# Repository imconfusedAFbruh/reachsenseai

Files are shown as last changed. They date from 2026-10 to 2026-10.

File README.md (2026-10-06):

# ReachSenseAI

**Behind-the-back shoulder flexibility, measured in 3D.**

ReachSenseAI is a research measurement instrument in development that uses an iPhone's front TrueDepth camera and calibrated finger fixtures to estimate the gap or overlap between two middle fingertips during a behind-the-back shoulder flexibility test.

The design pairs each score with evidence about alignment, tracking, stability, and calibration—giving researchers a measurement they can inspect, repeat, and export.

> **Project status:** the native front TrueDepth sensor prototype and tested geometry core are available. Full rigid-body tracking/fusion, physical fixture acceptance, and research validation remain in development. No final accuracy claim has been established.

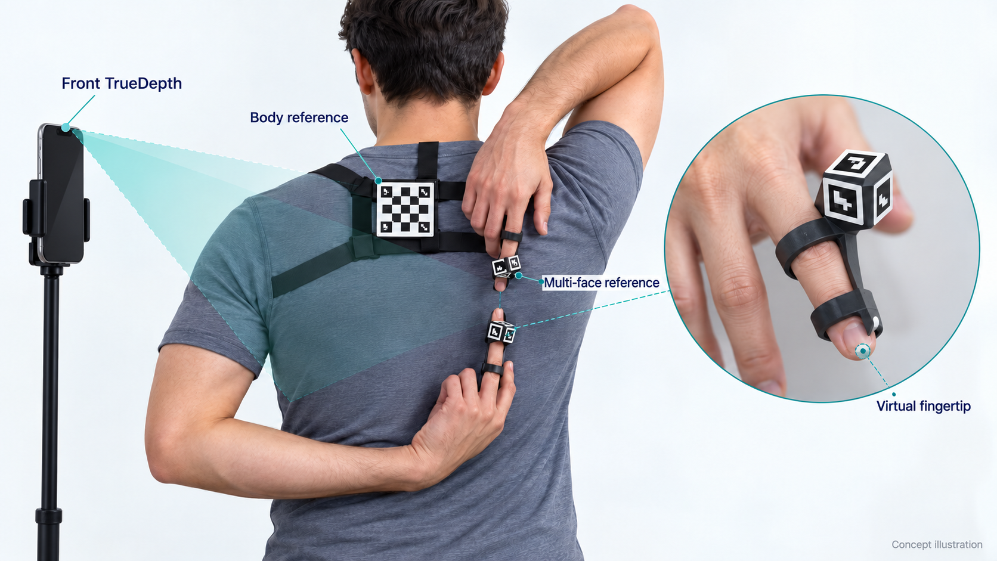
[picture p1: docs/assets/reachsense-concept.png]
ReachSenseAI concept showing a front TrueDepth camera on a stand, calibrated upper-back reference, multi-face middle-finger fixtures, and a virtual fingertip close-up


*Concept illustration of the planned setup. Fixture shapes, marker patterns, and mounting are illustrative; final geometry and performance require experimental validation.*

## What it measures

The participant reaches one hand down from above the shoulder and the other up from below. ReachSenseAI estimates the anatomical middle-finger endpoints in a coordinate frame registered to the participant's back.

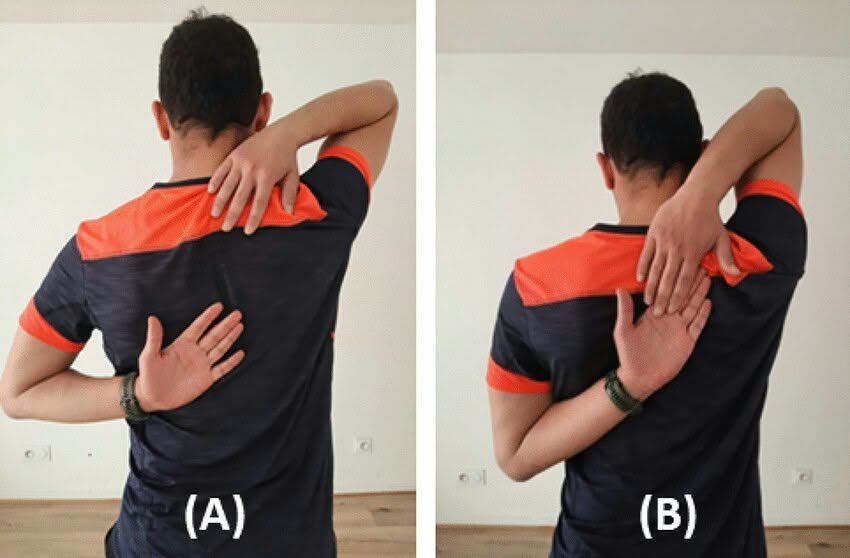
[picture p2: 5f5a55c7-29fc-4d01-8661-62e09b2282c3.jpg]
Reference illustration of the behind-the-back shoulder flexibility test


The primary score is **signed overlap along the body's upward axis**:

| Score | Meaning |
| --- | --- |
| Negative | A projected gap between the endpoints |
| Zero | Equal positions along the body axis |
| Positive | Projected overlap between the endpoints |

Sideways and depth offsets are recorded separately. Zero projected overlap does not establish physical contact, and fingers that appear aligned in an image may still be apart in depth.

## Designed for the difficult part of the test

### Fingertips can disappear without losing their reference

Overlap can hide one or both biological fingertips. Each fixture provides a calibrated virtual fingertip point, allowing its location to remain estimable while enough of the rigid reference is observed. If the reference becomes unobservable, the frame is rejected; a predicted point cannot silently become a valid measurement.

### Several faces contribute to one pose

Each finger fixture carries at least three uniquely identified markers on differently oriented faces. All usable visible corners contribute to one common 6-DoF rigid-body pose. Alternative faces provide observations during rotation and partial occlusion, with acceptance based on geometry, pose conditioning, residuals, and depth support rather than marker count alone.

### Depth adds a geometric check

Synchronized RGB and TrueDepth observations constrain the same known fixture geometry. Image corners, local depth surfaces, and temporal evidence contribute through quality-weighted fusion. Sensor disagreement and poor alignment trigger quality checks before a score is accepted.

### The score follows the participant's frame

A ChArUco reference on a calibrated upper-back mount establishes the body coordinate frame. The measurement is designed to account for camera tilt and participant orientation within validated conditions, rather than depend on a pixel gap in the camera image.

### Anatomical registration is part of the instrument

The proposed dorsal finger fixtures use two separated registration regions and a gentle fingertip stop. Their endpoint relationship, remount repeatability, and effects on posture and comfort must be tested. The upper-back mount receives its own registration calibration and drift checks.

### Every result has a record

The planned research exports include successful and unsuccessful attempts, per-frame geometry, quality metrics, rejection reasons, device details, and calibration and threshold versions. Summary CSV and detailed JSON support analysis and investigation of how a result was obtained.

## Measurement workflow

1. The researcher assigns one hand-up position per participant and keeps it consistent across visits.
2. With the phone on a stand, the researcher verifies calibration, fixture assignments, mounting, and fingertip seating.
3. After a familiarization attempt, the researcher starts each scored attempt. The app is designed to capture the median score over **one continuous second of passing observations**.
4. The researcher confirms seating after capture. A fixture swap or movement invalidates the affected trial and requires correction before restarting.
5. Up to **five scored attempts** are allowed to obtain **three valid trials**. Their median becomes the session score; an incomplete set receives no session score.

The provisional acquisition timeout is 15 seconds. Rest is researcher-controlled, and inter-attempt intervals are logged. Optional RGB/depth recording requires participant consent, uses local storage, and is retained indefinitely when enabled. Recorded media are included in exports only when explicitly selected.

## From observations to a score

```mermaid
flowchart TD
    Phone["iPhone front TrueDepth"] --> RGB["Synchronized RGB"]
    Phone --> Depth["Depth observations"]
    RGB --> Tags["Visible hand-fixture corners"]
    RGB --> Board["Observed ChArUco reference"]
    Geometry["Calibrated multi-face geometry"] --> Pose
    Tags --> Pose["One common pose per hand rigid body"]
    Depth --> Surfaces["Registered per-face 3D surfaces"]
    Pose --> Fusion["Quality-weighted pose fusion"]
    Surfaces --> Fusion
    Fusion --> Tips["Estimated virtual anatomical fingertips"]
    TipCalibration["Physical-jig endpoint calibration"] --> Tips
    Board --> Body["Registered body frame"]
    MountCalibration["Board-to-body mounting calibration"] --> Body
    Body --> Transform["Transform both tips into body coordinates"]
    Tips --> Transform
    Transform --> Score["Signed body-Y overlap + lateral/depth offsets"]
    Score --> QC{"Current observations and quality checks pass?"}
    QC -->|Yes| Window["Continuous 1-second window: median score"]
    QC -->|No| Reject["Reject frame; reset stable window"]
    Reject -. "Reacquire within attempt timeout" .-> Tags
    Window --> Seating{"Post-trial seating confirmed?"}
    Seating -->|Yes| Trial["Accepted trial"]
    Seating -->|No| Invalid["Invalidate attempt"]
    Trial --> Session["Median of 3 valid trials within 5 attempts"]
    Session --> Export["Summary CSV + detailed JSON"]
    Reject -. "Preserve failure evidence" .-> Log["Attempt and per-frame research records"]
    Invalid --> Log
    Log --> Export

    classDef sensor fill:#e8f5f4,stroke:#147d83,color:#123c43
    classDef calibration fill:#eef0fa,stroke:#626bb0,color:#293255
    classDef output fill:#e5f3e9,stroke:#39835a,color:#174329
    classDef failure fill:#fff0ee,stroke:#bd6258,color:#6f302b
    class Phone,RGB,Depth sensor
    class Geometry,TipCalibration,MountCalibration calibration
    class Trial,Session,Export output
    class Reject,Invalid failure
```

Current observations are required for both hand rigid bodies and the body reference. Temporal prediction can assist tracking, but cannot supply a valid measurement. An incomplete three-trial set has no session score; its attempt records remain exportable.

The planned implementation uses native iOS sensor processing with Swift, OpenCV, and AVFoundation/ARKit as appropriate to verified device support. Core measurement does not depend on AI hand-landmark estimation or cloud processing.

## Validation before performance claims

The next development gate is **physical finger-fixture feasibility**, supported by minimal capture and detection tooling. Marker dimensions, mounting geometry, sensor support, and usable observation conditions will be established experimentally.

Bench validation covers known distances, hand and body rotation, depth offsets, partial and complete reference occlusion, pose observability, and palm-to-palm overlap. Provisional engineering targets are MAE ≤ 5 mm, absolute bias ≤ 2 mm, and repeated static measurement SD ≤ 2 mm. These are requirements to test, not demonstrated performance.

Scored human research follows bench acceptance. Human repeatability and equipment effects must then be assessed. Published reference categories require additional evidence that their test definition matches the instrument's projected-overlap score.

## Explore the project

The [Android dual-camera APK](android/README.md) on `develop/android-dual-camera` tests simultaneous rear wide/ultrawide capture on the Samsung Galaxy S23 Ultra and exports timing evidence. GitHub Actions builds it from Windows without a local Android toolchain. Physical camera support and exposure synchronization still require checks on the phone; this capture app does not yet reconstruct stereo depth or issue a fingertip score.

Build the [native sensor prototype](ios/README.md) on a Mac with Xcode, then run it on the initial iPhone 15 Pro Max to record feasibility observations. The simulator cannot supply TrueDepth data. Inspect the adjustable [finger-fixture candidate and STL](hardware/README.md), and use the [frame inspection tool](scripts/feasibility/README.md) for exported bench observations. Follow the [implementation ledger](docs/implementation-progress.md) for verified software evidence and open physical/device gates.

| Document | Contents |
| --- | --- |
| [Measurement plan](plan.md) | Hardware, acquisition, geometry, QC, calibration, validation, and milestones |
| [Design decisions](docs/design-decisions.md) | Agreed protocol and architecture amendments |
| [Glossary](GLOSSARY.md) | Canonical measurement and instrument terminology |
| [Architecture decisions](docs/adr/) | Reasons behind consequential design choices |

Start with the measurement plan for the reproducible methodology. The current app is a sensor feasibility tool; it does not yet produce a shoulder-flexibility score.

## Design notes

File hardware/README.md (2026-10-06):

# Finger-fixture feasibility gate

The next physical gate is a repeatable anatomical relationship between each middle fingertip and its multi-face rigid reference. This directory supplies an adjustable CAD candidate and nominal geometry for experiments, not a validated or participant-ready fixture.

## Candidate design

`finger_fixture.scad` has two separated dorsal half-ring supports, retention slots, a bridge, a gentle fingertip stop, and a three-face marker mount. Candidate defaults are an 8 mm finger radius, 18 mm support spacing, 10 mm marker edges with 2 mm quiet-zone margins, and 35-degree side faces. These dimensions must be adjusted after fit, visibility, mass, comfort, and overlap tests. The mesh has no claim of joint immobilization or anatomical rigidity.

The physical frame R has origin at the nominal tip stop, +Y toward the distal fingertip, +Z dorsal, and +X lateral. Nominal face transforms and canonical corners come from the same dimensions. Actual prints, adhesive thickness, marker orientation, liner/strap choices, and fingertip registration require measurement and calibration.

```sh
python -m hardware.fixture_layout --output-dir hardware/generated/upper-candidate
python -m hardware.fixture_layout --radius-mm 9 --ids 31 32 33 \
  --output-dir hardware/generated/lower-candidate --openscad /path/to/openscad
```

Use OpenSCAD 2021.01 or newer to inspect/adjust the source and generate STL. Generated layout JSON is explicitly marked `candidate-unmeasured-not-valid-for-scoring`; it must not be passed off as verified jig calibration. Print the [candidate marker sheet](prototypes/marker-sheet.svg) at 100% and independently measure its black edges. [Marker generation/detection tools](../scripts/feasibility/README.md) support alternate experimental dimensions and dictionaries. Canonical marker tops must point toward fixture +Y for this nominal layout; verify actual mounting transforms.

## Required experiments before expanded fusion work

1. Measure actual finger/contact dimensions and select retention/liner materials. Document which middle/distal regions the supports register and which motions can alter the endpoint.
2. Independently measure virtual endpoint drift under insertion, finger flexion/rotation, sliding, repeated remounting, and palm-to-palm overlap. Separate mechanical movement from optical pose error.
3. Check hand/finger reach and comfort against the intended test; the stop/supports may change posture or prevent bare-finger contact. Record that equipment effect rather than assuming equivalence.
4. Test tag image area, corner geometry, blur, incidence angle, depth coverage, and occlusion at candidate camera distances. Establish usable observations from conditioning/residuals/depth support.
5. Measure every face transform and the anatomical endpoint in the common frame for each physical jig. Version the verified calibration and record jig identity, marker IDs/dictionary, marker orientation, geometry and verification evidence.
6. Prototype/calibrate a repeatable upper-back harness or multi-contact mount, including board-to-body registration and remount/angular drift.

Only demonstrated registration, visibility, and comfort evidence advances the physical gate. CAD rendering or passing software tests alone does not satisfy it.

## Rendered candidate

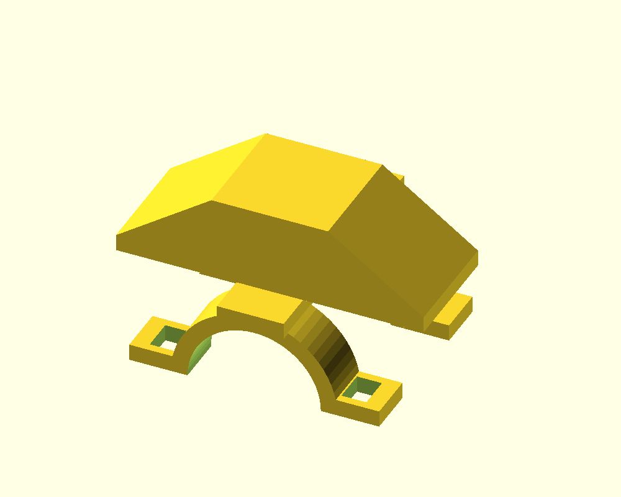
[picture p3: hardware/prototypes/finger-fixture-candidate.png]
Nominal finger fixture candidate


[STL mesh](prototypes/finger-fixture-candidate.stl) | [nominal face layout](prototypes/candidate-layout.json). Generated from the source with OpenSCAD 2021.01. The STL has 620 triangles, closed two-face edge topology, and nonzero volume. This is mesh evidence only; physical fit, seating rigidity and calibration remain untested.

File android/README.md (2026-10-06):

# ReachSense Dual for Android

This branch builds an Android APK that tests simultaneous rear wide/ultrawide capture on the researcher's Samsung Galaxy S23 Ultra. It uses one Camera2 logical session with two explicitly selected physical-camera YUV outputs. Device support is discovered and tested at runtime; a phone model or successful CI build is not hardware verification.

## Get the APK from Windows

1. Open [Android dual-camera APK runs](https://github.com/imconfusedAFbruh/reachsenseai/actions/workflows/android.yml), selecting the `develop/android-dual-camera` branch.
2. Open a successful run and download its **ReachSenseAI-android-debug** artifact. Extract the ZIP; the installable file is **ReachSenseAI-dual-camera.apk**.
3. Transfer the APK to the S23 Ultra and open it. Allow installation from the app opening the APK when Android requests it, then allow camera permission in ReachSense Dual.

Each artifact includes signature/manifest evidence, the source commit, SHA-256 digest, and timing/report test results. This is a signed development APK. GitHub runners generate debug signing keys; subsequent builds can have a different key and require uninstalling the old app. **Export all retained reports before uninstalling**, which removes app-private storage. Stable private signing is required before relying on in-place upgrades across research builds.

Verified software build: [run 37545350657](https://github.com/imconfusedAFbruh/reachsenseai/actions/runs/37545350657), source `d15a6c0`, artifact **ReachSenseAI-android-debug**. Build, lint, assertion checks, signature and downloaded-file integrity checks passed. S23 Ultra hardware verification remains pending.

## Run the device check

1. Tap **Check cameras**. Select a candidate pair using the physical IDs and estimated FOV. Choose the main wide and ultrawide rather than either telephoto lens. IDs are discovered, not hardcoded.
2. Start a **30-second test**. Both previews must receive current frames. Previews are downsampled and rendered at up to 5 fps to reduce load; every acquired image's timestamp is retained before preview throttling. The observed capture cadence is reported separately.
3. Cover each rear lens individually. Only its assigned preview should be obstructed. Assign A/B to wide/ultrawide and confirm each covered-lens check while the run is active. Repeat a run if there was insufficient time to confirm.
4. Export the selected JSON report using Android's document picker. Capabilities, failed sessions, interrupted runs and successful captures remain separately selectable. No image pixels are stored or exported.
5. Review both stream counts and cadence, unmatched/overflow/rejected observations, capture failures, physical metadata availability, and synchronization classification. Session rejection, disconnect and a three-second stream stall terminate the run with a reason; an early Stop or backgrounding saves an interrupted run.

The pairing filter starts at 5 ms and is adjustable. It is exploratory, not a validated stereo threshold. Same-request image timestamps may be equal even when actual exposures are not synchronized. Missing physical metadata remains missing, and ambiguous timestamp associations are explicitly rejected. Exposure/frame durations, rolling-shutter skew and physical timestamps are retained when provided. Physical timestamp differences are calculated only when both sensors report the comparable REALTIME timestamp source.

If local storage fails, pending reports remain available across screen rotation and new checks are blocked until they are exported. Keep the app open and export every pending report: these fallback copies are in memory and cannot survive the app process being killed while storage is unavailable. Export failures leave the pending copy available for retry.

Approximate/unknown synchronization requires an optical timing experiment with a controlled flashing target or motion. Even hardware-calibrated synchronization needs optical checks and stereo calibration before declaring stereo suitability. This APK does not reconstruct depth, track fixtures or issue fingertip/clinical scores. It establishes capture evidence for that next stage.

## Build and checks

GitHub Actions requires no Android installation on the researcher's Windows computer. Pushes touching `android/` or its workflow trigger checks, build, lint, signature verification and artifact upload. Manual dispatch may require the workflow to exist on the default branch; branch pushes work for this development branch.

With Java 17 and an Android SDK installed, use Gradle 8.11.1: `gradle -p android assembleDebug lintDebug`. Build configuration pins AGP 8.9.2 and SDK/build tools 35. Runtime code uses only platform APIs, with API 28 as its minimum.

The standalone assertions in `checks/` exercise actual timing pairing and JSON report persistence without a camera or emulator. Their JSON test library is pinned to `org.json:json:20240303` and checksum-verified in CI; the APK uses Android's built-in JSON implementation. Real camera support, lens identity, stream timing and interruption behavior still require the S23 Ultra device checklist in the approved plan.

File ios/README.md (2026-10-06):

# Native sensor prototype

This is Milestone 1 software for front TrueDepth feasibility work. It is not yet the full measurement app and produces no flexibility score.

## Build from Windows with GitHub Actions

Open the [native workflow](https://github.com/imconfusedAFbruh/reachsenseai/actions/workflows/native.yml), choose **Run workflow**, select `develop/rgb-web` (which contains the IPA packaging update), and run it. The workflow runs Swift core checks, builds the Release iPhone app and simulator target on a cloud Mac, packages the device app, verifies the IPA structure and ARM64 executable, and uploads `ReachSenseAI-unsigned-<commit>` under the completed run's **Artifacts**.

Download and unzip that artifact ZIP to obtain `ReachSenseAI-unsigned.ipa`. This is an **unsigned native TrueDepth sensor prototype**, not the full measurement app or the browser application. It must be signed before installation. Windows users can sign and install it using [Sideloadly](https://sideloadly.io/) and their own Apple Account. Free-account signing requires periodic refresh; successful compilation/package verification does not establish physical-device capture support. Keep downloaded artifacts locally for your research; GitHub artifact retention is finite.

The build needs no Apple signing secrets or Apple Account credentials in GitHub. Research recording consent and local export behavior remain as described below.

First verified build, 2026-10-07: [run 37538730987](https://github.com/imconfusedAFbruh/reachsenseai/actions/runs/37538730987), source `ab7edecb703eadaa34a75b43c7a1d884e24b739d`. All workflow jobs passed. The downloaded IPA was independently checked on Windows for ZIP integrity, the iPhoneOS platform, camera permission description and ARM64 Mach-O executable. Size: 162,076 bytes. SHA-256: `c884a4224df2328e03b1a38dc07c1d3553c5f2395a552f3f41d24585196d6621`. Signing, installation and real-device capture remain unverified.

## Build locally on a Mac

Requires Xcode with the iOS 17+ SDK and XcodeGen 2.43 or newer. The app uses the local `ReachSenseCore` Swift package.

```sh
brew install xcodegen
cd ios
xcodegen generate
open ReachSenseAI.xcodeproj
```

Set your signing team in Xcode and run the `ReachSenseAI` scheme on the initial iPhone 15 Pro Max. Other models in the requested iPhone 15 Pro Max–iPhone 18 range remain candidates until exact-device runtime support and capture quality are verified. There is no rear-camera fallback. The simulator can check the build/UI but cannot supply TrueDepth observations.

## First-device acceptance

1. Grant camera permission and start capture. Confirm front RGB and depth views change together, unmirrored, with compatible raw orientation.
2. Verify hardware ID, dimensions, timestamp skew, received/dropped counts, calibration delivery, and valid depth coverage.
3. Inspect a known-distance bench target at 300, 400, 500, and 600 mm; these are candidate validation distances, not claimed operating guarantees.
4. Explicitly authorize bench/consented RGB-depth recording, enter independently measured reference distance and target/angle notes, and save repeated paired frames.
5. Share selected JSON files to a research workstation. They contain lossless RGB PNG, contiguous float32 little-endian depth, timestamps, intrinsics, extrinsics, forward/inverse lens-distortion data, and sensor accuracy/quality labels.
6. Deny permission, interrupt/background capture, stop/restart, and cover/remove targets. Verify stale/rejected previews clear, capture does not resume automatically after interruption, a pending permission grant cannot restart stopped capture, no stale frame is saved, and no invalid depth becomes a 3D point.

The point estimate uses reference-dimension-scaled intrinsics and inverse radial mapping from an observed distorted pixel to a rectilinear ray. Stored calibration must be verified against known geometry; sensor observations and software tests do not establish measurement accuracy. Depth filtering is disabled to retain invalid samples/noise for characterization. The 5 ms pair-skew limit is an acquisition diagnostic, not a bench-derived research-QC threshold.

Apple extrinsics describe camera-to-reference-camera geometry: translation is in millimeters and rotation is unitless; the reference camera is not assumed to be RGB. Exported depth and point coordinates are in meters.

Raw frames are saved under Documents/Feasibility with no automatic deletion. The app requests system backup exclusion on both the directory and each saved file; Apple treats this flag as backup guidance, not a guarantee against every backup method. There are no automatic app uploads. Researchers must control media consent and explicit exports. No recording happens merely by opening the camera preview.

## Automated verification

```sh
swift test --package-path ..
xcodegen generate
xcodebuild -project ReachSenseAI.xcodeproj -scheme ReachSenseAI \
  -destination 'generic/platform=iOS' CODE_SIGNING_ALLOWED=NO build
```

CI exercises the core behavior and compiles both device and simulator targets; physical-camera acceptance remains mandatory.

Calibration conventions follow [Apple camera extrinsics](https://developer.apple.com/documentation/avfoundation/avcameracalibrationdata/extrinsicmatrix). Backup handling follows [Apple backup guidance](https://developer.apple.com/documentation/foundation/optimizing-your-app-s-data-for-icloud-backup).

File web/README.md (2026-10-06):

# ReachSense RGB Lab

Static browser research prototype on the `develop/rgb-web` branch. GitHub Pages serves it; a dedicated worker processes RGB camera frames locally using pinned OpenCV.js 4.13. No server image processing or TrueDepth access is involved.

```mermaid
flowchart LR
  RGB[Calibrated RGB camera] --> Tags[ArUco corner detection]
  Geometry[Known noncoplanar fixture geometry] --> Pose
  Tags --> Pose[One common 6-DoF pose per fixture]
  Pose --> Tips[Calibrated virtual fingertips]
  Back[Calibrated body-reference pose] --> Body
  Tips --> Body[Participant body frame]
  Body --> Score[Signed lower-Y minus upper-Y overlap]
  Score --> QC[Quality + alignment + one-second window]
  QC --> Record[Operator seating check + local record]
```

Import a schema-1 JSON calibration bundle, enter the participant's anonymous study ID, choose the camera and confirm its lens/settings match calibration. Start the camera, check physical assignments and fingertip seating, then start each attempt. Confirm seating again after automatic capture. Three valid trials produce a position-specific median; five scored attempts without three valid trials leave the position incomplete. Familiarization is recorded separately. Stop or report changed assignments to invalidate and pause the affected attempt.

The supplied `examples/exploratory.json` demonstrates the format only. It is **not a camera or anatomical calibration** and cannot produce accepted trials. Actual camera intrinsics/distortion, metric face corners in detector corner order, anatomical fingertip offsets, fixture versions, body registration and bench-derived quality thresholds must be supplied by the researcher. Verified camera/fixture statuses, fixture evidence, body registration evidence and a validated threshold profile with evidence are required to enable research acceptance. These declarations are researcher-controlled; the software does not independently certify them.

Initial support requires three-dimensional, noncoplanar visible geometry for each hand fixture and the body reference. Planar-only observations are rejected. The solver checks joint reprojection residuals, normalized pose-Jacobian conditioning, positive camera depth and three LM starting points for competing poses. **This multistart check is not an exhaustive proof of unique pose.** Bench validation must establish supported visibility and conditioning limits. No predictions replace missing observations. ΔX and ΔZ are reported separately; zero projected Y does not imply contact.

Camera bindings include resolution and operator confirmation of lens, focus, zoom, crop and mounting. The browser cannot reliably lock or identify all optical settings on every device. Any incompatible setting or fixture/endpoint movement requires recalibration. Browser estimates lack independent depth evidence. Phone performance, physical accuracy, repeatability, equipment effects and compatibility with clinical norms remain unverified. The 10–15 processed fps objective is provisional. The live UI reports actual throughput, compute time and observation age.

IndexedDB retains sessions without automatic deletion, but browsers can evict storage. Export JSON for durable per-frame poses, quality, failures and full calibration records; CSV provides attempt summaries. Optional consented RGB snapshots are stored only for attempts when consent is selected before capture, with indefinite local retention; JSON includes them only when explicitly selected for export. No RGB video or depth recordings are implemented. Saved records remain available to exports after reload. A storage error stops capture and allows emergency export of the in-memory session.

## Checks and local preview

`npm ci`, `npm test`, `npx playwright install chromium`, `npm run browser-test` from this folder. Serve this folder through a local HTTP server, for example `python -m http.server 8080 --directory web` from the repository root. Camera access requires localhost or HTTPS. Assets use relative URLs for the GitHub Pages project subpath.

GitHub Actions runs the core and actual browser checks and publishes this folder from `develop/rgb-web`. The native instrument remains a separate architecture on the main branch.

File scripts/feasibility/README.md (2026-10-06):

# Feasibility observation tools

Python 3.10+ is sufficient; there are no third-party dependencies.

```sh
python -m scripts.feasibility.inspect_frame path/to/frame.json
python -m scripts.feasibility.inspect_frame path/to/frame.json --extract-dir data/raw/frame-001
```

This decodes the iOS export, verifies format/units/dimensions, retains invalid sensor values in the raw binary, and reports robust center-region depth statistics. Optional extraction writes lossless RGB, contiguous float32 little-endian depth, and capture metadata into a new directory.

Only add `--reference-is-axial-plane` when the entered independent reference is the axial camera depth of a planar target that fills the analyzed region. The default report deliberately gives no bias estimate. Relative sensor depth never produces a metric-bias claim. Spatial depth SD within one image is not temporal sensor repeatability or fingertip measurement accuracy.

Collect repeated physical observations at candidate distances, angles, and surfaces. Use recorded timestamps/device IDs/calibration to investigate synchronization, invalid-depth coverage, bias, and remount effects. No sample export or fabricated validation dataset is supplied.
# Marker experiments

Install the pinned OpenCV tool dependency in a virtual environment:

```sh
python -m venv .venv
# Windows: .venv\Scripts\activate; macOS/Linux: source .venv/bin/activate
python -m pip install -r scripts/feasibility/requirements.txt
python -m scripts.feasibility.markers generate --output-dir hardware/generated/artwork
python -m scripts.feasibility.markers detect observation.json \
  --expected-ids 21 22 23 31 32 33
```

Generation writes an A4 SVG and an artwork manifest. The default candidate uses `DICT_4X4_100`, IDs 21/22/23 and 31/32/33, a 10 mm black marker edge (including its black border), and a 2 mm white quiet zone on every side. Dictionary, IDs and dimensions are configurable for experiments. IDs must remain unique across both jigs and the eventual body reference. The checked-in [candidate sheet](../../hardware/prototypes/marker-sheet.svg) is ready for printing at 100% scale; measure the actual black edges afterward. Quiet zones must remain white and unobstructed. This artwork is not measured fixture calibration.

Mount each marker with its canonical top pointing toward fixture +Y, as assumed by the candidate geometry. Confirm the ID, dictionary, orientation and measured face transform in calibration; do not infer them from a rendered illustration or printed label.

Detection accepts an RGB PNG/JPEG or one native feasibility JSON export. It reports subpixel-refined canonical corners in order TL/TR/BR/BL, marker area, minimum edge length, expected-ID flags, duplicate IDs and rejected quadrilaterals. Corner coordinates refer to the raw distorted RGB image; a rotated marker's canonical TL is not necessarily the image's top-left corner. These are image observations, without pose estimation or depth fusion. `measurement_valid` is always false. Detector defaults are not validated research thresholds, and no visible-tag count establishes reliable rigid-body observability.

By default the report prints to stdout without storing another image. Explicit `--output-dir NEW_DIRECTORY` saves a JSON report and an RGB annotation; use only authorized bench/consented images. Existing output directories are refused. Reports include OpenCV/NumPy versions, source SHA-256, and the original frame ID for native exports. Retain the source export to recover its calibration and sensor metadata.

For fixture testing, record distance, lighting, incidence angle, hand configuration, blur and occlusion along with the observations. Determine supported conditions experimentally. Digital marker checks do not establish physical detection performance, image/depth registration, endpoint rigidity or instrument accuracy.

Marker generation, canonical corner ordering and detection follow [OpenCV's ArUco documentation](https://docs.opencv.org/4.13.0/d5/dae/tutorial_aruco_detection.html).

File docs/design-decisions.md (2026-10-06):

# Design interview decisions

This log records the grill-with-docs decisions and their subsequent amendments. Later decisions supersede conflicting earlier entries. The user's latest attached instruction authorizes reconciliation of the methodology with the multi-marker architecture; experimental prerequisites remain unverified and software implementation is outside this documentation update.

## Round 1 — Accepted

1. Report an anatomical fingertip score using calibrated jig geometry; distinguish the jig tracking reference from the anatomical endpoint.
2. Accept two finger caps and a back reference for the first research prototype, and experimentally assess their effects on reach and comfort.
3. Make the first release a research measurement tool. Export the signed score and quality evidence; defer fitness categories until the reference table's source, units, applicable population, and boundaries are established.
4. Begin with a fixed phone stand and a trained operator.

## Round 2 — Accepted

5. Define the anatomical endpoint as the furthest point along the middle finger's length. Seat it gently against the cap's internal stop, calibrate the stop relative to the marker, and check seating before each trial.
6. Define the primary score as signed body-Y overlap: negative for a projected gap and positive for projected overlap. Report sideways/depth offsets separately and reject poses outside validated alignment limits. Zero projected overlap does not establish physical contact.
7. Measure right-hand-up and left-hand-up positions separately. Record the upper hand for every trial and do not average results across positions.
8. Assess equipment effects as a separate validation requirement. Describe measurements as a jig-assisted test and defer comparison with bare-hand reference categories until equipment effects are assessed.

## Round 3 — Accepted and pending

9. Accepted in round 4: provisional bench engineering targets are MAE <= 5 mm, absolute bias <= 2 mm, and static repeated-measurement SD <= 2 mm across agreed test conditions. These are requirements to test, not demonstrated accuracy claims. Report rejection/failure rates alongside accepted-measurement accuracy.
10. Use one familiarization attempt followed by three valid trials per position. Save every trial, including unsuccessful attempts, and use the median of the three valid trials as that position's session score.
11. Invalidate an affected trial if a cap shifts, reseat the cap, and restart. Require an operator seating check before and after each trial; marker visibility alone does not prove anatomical seating.
12. Always retain per-frame geometry, quality metrics, rejection reasons, and calibration identifiers. RGB/depth recording is an explicit research option requiring participant consent, local storage, and a defined retention period; that period remains unresolved.

## Round 4 — Accepted and pending

13. Allow at most five scored attempts per position to obtain three valid trials. Preserve all attempts. If fewer than three trials are valid, mark the position incomplete and do not issue a position session score. The familiarization attempt is separate from the scored-attempt limit.
14. The researcher operates the phone on the fixed stand. In round 6, the user selected one hand-up position per participant, kept consistent across visits. This supersedes Q7's requirement to measure both positions; record the selected upper hand. Starting-side balancing was not accepted.
15. Store retained research data, including optional RGB/depth recordings, indefinitely. This supersedes the unresolved retention period in Q12; optional recording still requires explicit participant consent and uses local storage. No automatic time-based deletion is planned.

## Round 5 — Accepted and pending

16. Rest between attempts is left to the researcher's discretion. No fixed or minimum rest interval has been accepted.

## Round 6 — Accepted and pending

17. No exact iPhone model has been selected. In round 7, front TrueDepth was confirmed as the prototype sensor requirement; verify synchronized RGB/depth capture support on the selected device before implementation proceeds beyond feasibility work.

## Round 7 — Accepted and pending

18. Keep front TrueDepth as the prototype requirement and confirm capture support on the chosen device before proceeding.
19. The researcher assigns each participant's hand-up position under the study protocol, records the upper hand at enrollment, and keeps it consistent across visits.
20. Notify and pause if jigs are swapped during the same session, invalidate the affected trial, and require the researcher to confirm jig assignments and seating before restarting. Calibration stays attached to the physical jig ID.

## Round 8 — Accepted

21. Use provisional test ranges of 300–600 mm camera distance and -100 to +100 mm signed body-Y overlap. Evaluate the accepted accuracy targets throughout the ranges and narrow the supported operating range if validation fails.
22. Block measurement when a required jig calibration is missing or its geometry has changed. Store a calibration version with every trial, and require recalibration after marker movement, damage, or endpoint changes.

## Round 9 — Accepted and pending

23. Derive quality thresholds from bench validation and version them. Prevent overrides from producing valid scores, and allow failed attempts to be saved for investigation.
24. Require one continuous second of passing quality checks for capture. Any required check failure breaks continuity and requires a new passing interval. Within-window aggregation was accepted in Q27.
25. The researcher starts each attempt, the app captures automatically when a valid stable window is available, and the researcher then confirms seating. Acceptance remains subject to the previously required before/after seating checks.
26. Accepted in round 10: export summary CSV plus detailed JSON containing all attempts, per-frame geometry, quality metrics, rejection reasons, selected upper hand, device details, and calibration/threshold versions. Include optional RGB/depth recordings only when explicitly selected for export.

## Round 10 — Accepted

27. Use the median signed body-Y overlap across the continuous one-second passing window. Restart the window after a required quality check fails. Accept the captured trial only after the post-trial seating check passes.
28. End an attempt after a provisional 15 seconds without successful capture, preserve it as unsuccessful with its failure reasons, and count it toward the five-scored-attempt limit. The researcher can stop earlier. The timeout applies to acquisition, not the subsequent seating confirmation.

## Round 11 — Accepted and pending

29. Require static-distance, depth-offset, and rotation bench acceptance before scored human research measurements. Permit consented setup and comfort pilots earlier but label their measurements exploratory. After bench acceptance, assess human repeatability and equipment effects before accuracy claims or comparison with bare-hand reference categories.
30. Select marker dimensions, cap sizes, endpoint materials, and back-reference mounting through feasibility experiments. Require marker visibility throughout the pose, repeatable fingertip seating, secure back-reference mounting, and acceptable comfort. Document chosen geometry and calibration before bench validation.
31. Accepted after clarification: automatically record attempt timestamps and the interval from the end of one attempt to the start of the next. Rest duration remains at the researcher's discretion; the recorded interval is elapsed time between attempts and may include setup or adjustments.

## Outstanding branches

None at the current design level. The subsequent methodology-update instruction authorizes document reconciliation; experimental prerequisites below remain required work.

## Final architecture amendment — Authorized methodology update

The attached methodology instruction replaces the original single-marker-per-fingertip architecture with two rigid 3D structures, each containing at least three uniquely identified planar fiducials on differently oriented faces. Estimate one common pose from all usable visible corners and per-face depth geometry; do not average independent marker poses. Calibrate every face transform and the virtual anatomical endpoint in a common frame for each physical jig.

Biological fingertip visibility is not required. Sufficient current observations of both rigid bodies and the body reference are required for valid frames; purely predicted or extrapolated points cannot enter the measurement window. Expand validation to hand rotation, marker-face occlusion, hidden fingertips, overlap/palm-to-palm poses, depth offsets, and body rotation, and report performance by visibility and viewing conditions.

Retain the finalized one-second continuous median, trial/session workflow, indefinite retention, and explicit optional media export. Retain Q6's zero-as-equal-body-Y definition rather than the attachment's illustrative zero-as-touch wording, because projected overlap alone does not establish physical contact. Dimensions, minimum usable face visibility, optimizer details, and quality thresholds remain experimental choices. The update preserves the research objective and the 30-section plan structure.

## Methodology review refinements

1. Prototype a dorsal finger fixture with at least two separated anatomical registration regions, such as the middle and distal phalanges, plus the fingertip stop. Verify resistance to endpoint-changing flexion, rotation, and sliding; multiple supports do not establish rigidity without evidence. Evaluate posture/reach and comfort effects independently.
2. Require measurement-definition equivalence with any source normative test, in addition to equipment-effect validation, before applying its categories. Preserve ΔX/ΔZ to investigate alignment-dependent disagreement.
3. Treat the upper-back mount as a calibrated fixture with repeatable harness/multi-contact registration, a versioned board-to-body transform, and drift/remount verification. A visible board or clothing attachment alone does not establish anatomical alignment.
4. Add a dedicated complete rigid-body observability experiment. Derive acceptance from conditioning/ambiguity, reprojection residuals, observed corner geometry, and depth support rather than marker count alone; validate the rule on separate conditions/repetitions.
5. Make physical finger-fixture feasibility the next development gate. Permit minimal sensor/detection tooling to support experiments, while deferring expanded software and finalized dimensions until registration evidence supports the fixture.

## Experimental prerequisites after review

The following are intentionally determined by feasibility work and validation, not assumed to be settled design values:

- Exact iPhone model and verified front TrueDepth capture support.
- Marker dimensions, endpoint materials, cap sizes, and reference mounting geometry.
- Calibration verification procedures, jig seating/remount repeatability, and marker visibility across the pose.
- Bench-derived quality limits, including lateral/depth alignment limits, with versioned threshold sets.
- Detailed validation conditions, equipment effects, and compliance with provisional accuracy targets.

Neither the design interview nor the methodology update certifies these prerequisites as achieved. Record their procedures and results before treating the instrument as validated.

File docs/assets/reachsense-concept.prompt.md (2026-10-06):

# ReachSenseAI concept image provenance

Created with the built-in image generation tool, then corrected with its image-editing mode. The README uses `reachsense-concept.png`. This is an illustrative hardware concept, not a validated fixture design; marker patterns are not printable calibration targets.

## Initial generation prompt

```text
Use case: scientific-educational
Asset type: landscape hero illustration for the ReachSenseAI GitHub README.
Create a polished, anatomically coherent scientific product-concept illustration of a behind-the-back shoulder flexibility measurement setup. Wide landscape layout, clean light background, restrained teal and navy accents, soft studio lighting, precise semi-realistic 3D illustration.
Main scene: rear three-quarter view of one adult participant in a plain close-fitting shirt. The right arm reaches over the right shoulder with the hand pointing downward along the upper back; the left arm reaches upward from the waist with its hand pointing upward. The two middle fingers approach each other at mid-back. Both hands must have natural anatomy and five fingers. Each MIDDLE FINGER wears a small lightweight dorsal rigid fixture with two separated support regions and a fingertip stop. Each fixture carries a compact three-dimensional target with THREE distinct black-and-white square fiducial faces on differently oriented planes; do not use just one flat tag. A separate small ChArUco checkerboard reference is on the upper back, mounted by a lightweight repeatable harness, above and clear of the hands.
At the left of the composition show an iPhone on a fixed slim stand behind the participant, front screen/front sensor side aimed at their back. A faint translucent field-of-view cone links the front sensor to the targets; it represents the camera viewing volume, not vision through skin.
At the right show a clean close-up inset of the dorsal middle-finger fixture: clearly show two separated supports, three marker faces, and a tiny teal dashed virtual point at the distal anatomical fingertip. A thin dotted connector links inset to the fixture in the main scene.
Minimal exact text labels only: "Front TrueDepth", "Multi-face reference", "Body reference", "Virtual fingertip". Small unobtrusive footer: "Concept illustration".
Important: no numeric measurements, no accuracy claim, no app UI, no fake clinical ratings, no X-ray or seeing through a hand, no magical beam, no surgery, no anatomy errors, no extra arms, no floating marker cubes unconnected to fingers, no oversized targets blocking contact. This is an experimental hardware concept, not a finished device photograph. Keep all labels readable and lines uncrowded.
```

## Final correction prompt

```text
Edit this scientific ReachSenseAI concept illustration. Keep the participant pose, clean landscape composition, two finger fixtures, fixture close-up, colors, and overall typography. Make two precise corrections: (1) The phone on the stand must show its FRONT glass screen, notch/front sensor side facing the participant, with the viewing cone originating at the front TrueDepth sensor. Remove the visible Apple back logo and rear camera module; do not show or use rear cameras. A slight three-quarter angle may show the front dark glass screen clearly while pointing toward the participant. (2) Correct leader lines: the exact label 'Multi-face reference' must point clearly to the three-faced target on the UPPER middle-finger fixture, not the checkerboard on the back. The exact label 'Body reference' must point clearly to the ChArUco checkerboard on the back, not a strap. 'Front TrueDepth' must point to the front sensor at the top of the phone; keep 'Virtual fingertip' pointing to the inset's dashed tip point. Preserve 'Concept illustration' footer and all other details. No numeric accuracy claims. Make these corrections anatomically and physically coherent.
```

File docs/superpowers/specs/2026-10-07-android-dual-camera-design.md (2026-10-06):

# S23 Ultra dual-camera capture APK

## Approved scope

Build an installable Android application through GitHub Actions, targeting the researcher's Samsung Galaxy S23 Ultra. The first APK tests simultaneous rear wide and ultrawide capture and collects timing evidence for future stereo matching. The user approved this scope on 2026-10-07. This is a new Android capture subsystem on `develop/android-dual-camera`; existing iOS and browser implementations remain available.

Stereo reconstruction, fixture tracking, virtual fingertip measurement, and clinical scores are subsequent work. Existing anatomical endpoint, calibration, trial, and validation definitions in `GLOSSARY.md` and `docs/design-decisions.md` still govern that future work. Dual RGB capture does not supply TrueDepth measurements or establish measurement accuracy.

## Capture and device discovery

Use native Android Camera2 and platform UI, with no camera abstraction library. Require Android 9/API 28 or later; record the actual Android version, model, build fingerprint, app version, and source commit in each report.

Enumerate rear logical cameras and their physical camera IDs. Display candidate lenses using focal lengths, sensor dimensions, and estimated field of view. Do not hardcode S23 camera IDs or equate two arbitrary cameras with wide and ultrawide. The researcher selects a pair and confirms lens identity by covering each physical lens while observing both labeled previews. Until confirmed, identify the outputs by physical ID rather than asserting lens identity.

Open one logical camera with two same-size YUV ImageReader outputs, each explicitly routed to a different selected physical ID through OutputConfiguration. Render both previews from those outputs rather than adding extra camera streams. Choose a modest common supported resolution and record its actual dimensions. Probe configuration support where available, then require successful session configuration and sustained frame delivery from both outputs. Stream presence alone is not proof of synchronized exposure.

If no suitable logical grouping, common size, or working simultaneous session exists, display the specific failure and retain an exportable capability report. Never silently replace dual capture with alternating cameras, duplicate one output, or declare support from the phone model alone.

## Timing evidence

Run a bounded 30-second verification capture, with an earlier Stop action. Keep every observed frame's stream ID, image timestamp, callback arrival time, sequence information when available, and associated physical capture metadata. Include sensor timestamps, exposure duration, frame duration, rolling-shutter skew, timestamp source, and logical-camera synchronization type. Represent missing metadata explicitly; callback arrival times are diagnostics, not exposure times.

Join image buffers to capture results using their documented timestamps; preserve ambiguous, missing, late, and unmatched associations as such. Pair frames one-to-one, without reusing a frame. Report matched and unmatched counts, per-stream cadence, observed gaps, capture failures, queue overflows, and timestamp differences. Distinguish observed gaps from proven sensor drops. Use bounded queues; retain overflow counters and rejection reasons instead of silently discarding evidence.

Expose a positive finite maximum pairing difference in milliseconds, initially 5 ms, and store the selected value with the report. This is an exploratory filter, not a validated stereo acceptance threshold. Same-request image timestamps can be identical even with approximate synchronization: a low image-timestamp difference must not produce an exposure-synchronization claim. Physical metadata differences are reported separately when available and comparable.

Show separate results for dual-stream delivery, operator-confirmed lens identity, and timing evidence. Report approximate/unknown synchronization as requiring an external exposure-timing test. Even calibrated synchronization and low measured skew establish only the reported capture evidence; future stereo suitability requires optical timing checks with motion or a controlled flashing target, calibration, and bench validation.

## UI, storage, and lifecycle

Provide device/pair selection, two labeled live previews, a timing summary, Start/Stop, lens-confirmation controls, and Export report. Use accessible native controls and clear camera permission failures. Stop and release camera resources on backgrounding; preserve an interrupted run with its reason. A stalled stream or camera disconnect ends the run as unsuccessful rather than displaying a pass.

Persist capability findings, settings, observed frame records, metadata, and failure reasons locally in app-private storage. Export JSON through Android's document picker without network access. Write completed/interrupted reports before replacing them; retain saved runs until explicitly deleted. The first APK does not persist participant imagery: previews remain transient. Any future image recording requires a separate explicit consent and recording workflow consistent with the project decisions.

## GitHub build and acceptance

Add an Android-only GitHub Actions workflow triggered by pushes to this branch and Android pull requests. Use pinned compatible Java, Gradle, and Android build tooling. Build a signed development APK, verify its signature and manifest, and upload the APK plus test/build evidence as artifacts. CI establishes build correctness, not S23 Ultra hardware verification. Document development signing and any upgrade limitations; users must export retained research reports before an uninstall required by a signing-key change.

Leave one small runnable timing-logic check covering one-to-one pairing, threshold boundaries, unequal frame rates, out-of-order/duplicate timestamps, and missing timing evidence. CI must run it and compile the APK. A device test then checks both covered-lens identities, sustained simultaneous delivery, interruption/stall handling, and exported report completeness.

No release is described as device-verified until the researcher runs the APK on the S23 Ultra and reviews the resulting report. No stereo or clinical accuracy claim follows from a successful build or a timestamp-only check.

## Primary API references

- [Camera2 multi-camera capture](https://developer.android.com/media/camera/camera2/multi-camera)
- [Synchronization and timestamp characteristics](https://developer.android.com/reference/android/hardware/camera2/CameraCharacteristics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)
- [Physical capture results](https://developer.android.com/reference/android/hardware/camera2/TotalCaptureResult#getPhysicalCameraResults())

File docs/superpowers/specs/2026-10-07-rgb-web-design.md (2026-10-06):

# ReachSense RGB web application

Status: approved and implemented as a research prototype. Branch: `develop/rgb-web`. Physical calibration, accuracy and phone performance remain validation gates.

## Intended outcome

Build a client-side application served by GitHub Pages. A single calibrated RGB camera observes known multi-marker 3D rigid fixtures. The app estimates one camera-relative 6-DoF pose for each physical fixture, transforms two calibrated virtual middle-fingertip endpoints into a participant-centered body frame, and reports their signed body-Y overlap in millimeters.

This is a separate RGB-only implementation of the existing measurement concept. Native TrueDepth acquisition is not a prerequisite for developing this branch. Depth-sensor fusion and depth-supported quality checks cannot be claimed by this implementation. Physical fixture calibration, anatomical seating and empirical measurement validation remain requirements for research results.

Keep the terminology in `GLOSSARY.md` and the endpoint, identity, assignment and protocol decisions in `docs/design-decisions.md`. This document changes the acquisition architecture for this branch; it does not silently replace the native methodology in `plan.md`.

## Recommended approach

Use static HTML/CSS and browser JavaScript, with a single pinned OpenCV.js runtime. Use its ArUco detector, calibrated projection and common-point PnP functions. A worker processes one current RGB frame at a time; discard obsolete queued frames rather than accumulate latency. The browser handles camera permission, configuration import, rendering, local persistence and exports. No server, account, cloud inference, framework or hand-landmark model is needed.

Alternatives considered:

- A JavaScript marker detector plus OpenCV.js PnP would require two libraries and a dictionary/corner-convention bridge. Keep it as a fallback only if the selected OpenCV.js artifact fails its runtime capability check.
- A custom OpenCV/WASM build could expose additional pose-solution APIs or reduce payload size, but adds a compiler/toolchain maintenance burden. Use it only if the pinned standard build cannot satisfy the required pose/ambiguity checks.

OpenCV 4.13's JS binding configuration lists ArUco detection, `solvePnP`, `solvePnPRansac`, `solvePnPRefineLM`, `Rodrigues` and `projectPoints`. Verify those actual browser APIs before choosing an artifact; source bindings alone do not prove runtime availability. Vendor the tested runtime and its license, record its version/digest, and serve it from the same Pages origin. Camera frames must never be sent to a third-party CDN or API.

## Body frame assumption for review

Use a third rigid marker reference on a repeatable upper-back mount, with known marker geometry and a calibrated reference-to-body transform. Positive body Y is superior along the torso, X is sideways, and Z is outward from the back. A visible reference does not prove correct anatomical mounting.

The initial supported reference, like the hand fixtures, must provide noncoplanar observed geometry that passes pose conditioning and ambiguity checks. An existing flat ChArUco board is not automatically interchangeable: supporting a planar reference requires a tested multi-solution disambiguation path. Until that exists, reject planar-only observations rather than substitute camera Y or a manually drawn image axis.

This assumption provides one common pose-estimation path for all three references. If the available body hardware is specifically a planar board, resolve that requirement before the implementation plan.

## Calibration contract

Import one versioned JSON bundle containing:

- Camera calibration ID/version, pinhole model, calibrated image width/height, matrix K, Brown-Conrady distortion coefficients, camera/lens identity and acquisition-mode/focus/zoom/orientation notes.
- A marker dictionary and globally unique marker IDs. Initially support the existing candidate `DICT_4X4_100`; use measured fixture files to choose final IDs and sizes.
- Two persistent physical finger-fixture IDs, calibration versions, measured canonical TL/TR/BR/BL marker corners in each common rigid frame, and the calibrated anatomical endpoint in that frame. Fixture millimeter geometry supplies metric scale.
- Body-reference identity/version, measured marker corners and a proper rigid transform mapping its reference coordinates into the anatomical body frame.
- Upper/lower assignments, selected hand-up position, and a versioned RGB-pipeline quality profile with validation provenance.

Validate finite numeric values, units, dimensions, positive focal lengths, supported coefficient counts/model, proper rotations, distinct IDs, nonzero/nondegenerate faces and endpoint/transform shape. Reject incompatible bundles with specific reasons. Missing camera/fixture/body registration prevents metric measurement. The checked-in CAD candidate is explicitly unmeasured; do not promote its nominal layout to verified calibration.

Bind calibration to the selected camera and acquired raw video dimensions. Processing resize may scale K by the known image transform, preserving the original calibration record. Do not silently accept changed camera modes, crop, zoom, focus or orientation. Stop measurement on camera/source changes and require setup reconfirmation; exposed track settings alone cannot certify unchanged optics.

Without a bench-validated quality profile, allow an explicitly exploratory geometry display/export but no accepted research trial or position session score. Record this distinction in exported data. TrueDepth-specific thresholds are not transferable to RGB by changing a label.

## Geometry pipeline

```mermaid
flowchart LR
  C[Calibrated RGB frame] --> D[Marker IDs and refined corners]
  G[Measured 3D fixture geometry] --> P
  D --> P[One common pose per observed rigid body]
  P --> Q[Current-observation and geometric quality checks]
  E[Calibrated virtual endpoints] --> T
  Q --> T[Transform endpoints into registered body frame]
  T --> S[Signed body-Y overlap and X/Z offsets]
  S --> W[Continuous stable-window and trial protocol]
```

For each fixture, collect all current recognized corners belonging to it into one 3D-to-2D correspondence set. Solve a common pose using calibrated intrinsics/distortion, reject incompatible marker observations, and refine the accepted joint pose. Do not independently solve markers and average their translations or rotations. Reject duplicate IDs and insufficient or geometrically ambiguous correspondences.

Use column-vector transforms with explicit directions. Let `T_C_R` map a hand rigid frame R to camera C, `T_C_F` map the body-reference fixture F to camera C, and `T_B_F` map F to the registered body frame B:

```text
p_tip_C = T_C_R * p_tip_R
p_tip_B = T_B_F * inverse(T_C_F) * p_tip_C
delta_B = p_lower_B - p_upper_B
D = delta_B.y
```

Use millimeters for all object geometry, translations, endpoints and results. Camera coordinates are x-right, y-down, z-forward. Camera Y must not be used as body Y. Physical fixture IDs remain distinct from assigned upper/lower roles.

Display D as signed body-Y overlap: positive projected overlap, negative projected gap, zero equal body-Y coordinates. Report delta-X and delta-Z separately; optionally show Euclidean separation as a diagnostic. Zero D does not establish physical contact.

Biological fingertips may be hidden. Their virtual endpoints remain usable only while sufficient current observations of both hand fixtures and the body reference pass the checks. Do not enter temporally predicted or extrapolated endpoints into measurement windows.

## Quality and observability

Per fixture, preserve contributing marker IDs/corners, inliers/outliers, reprojection RMS/max residual, minimum edge/image area, visible face normals, pose conditioning, ambiguity evidence and positive camera-depth checks. Inspect the complete correspondence geometry; marker count alone is not an acceptance rule.

The supported V1 path requires noncoplanar geometry, positive camera depth, consistent reprojection, a well-conditioned pose, and no unresolved competing solution. A solver returning success is insufficient. Verify runtime solver behavior and use deterministic alternative initializations/solutions where needed to expose ambiguity. If the selected runtime cannot supply adequate evidence, reject the case or choose the custom-build alternative; do not claim an ambiguity test that was never evaluated.

RGB-estimated delta-Z is a model-derived alignment quantity, not an independent depth observation. Assess it against known bench geometry. Log motion, body-reference stability, alignment offsets, current frame timestamps, staleness and dropped processing observations. Derive and version limits through RGB-specific bench validation. Engineering preview limits may be provisional but must remain excluded from accepted research scores.

Reset continuity on any rejected/late/missing required observation. Stop on hidden pages, camera interruption, permission loss or worker failure; clear stale overlays/results. Require explicit restart. Serialize start/stop so a late permission response cannot restart stopped capture.

## Operator workflow

1. Import calibration/profile, select the RGB camera and confirm the camera mode, physical fixture identities, body mount and anatomical seating.
2. Enroll a local participant identifier and researcher-assigned hand-up position. Keep the position consistent across visits.
3. Record a familiarization attempt, separate from scored attempts.
4. The researcher confirms pre-trial seating and starts an attempt. Capture the median D across one continuous second of passing observations. A failed check restarts that window.
5. End unsuccessful acquisition after a provisional 15 seconds or researcher stop. Preserve the attempt and failure reasons. A captured window awaits the post-trial seating check; capture alone does not accept it.
6. Obtain three valid trials in at most five scored attempts. Preserve every attempt. Use the median of three accepted trials; fewer than three yields an incomplete position without a session score. Rest remains researcher-controlled and inter-attempt intervals are logged.
7. Observed within-session role swaps pause capture and invalidate the affected attempt. Require confirmed assignment/seating before restart. Calibration stays attached to physical fixture identity.

No bare-hand normative categories or accuracy claim belongs in the initial app. Maintain the jig-assisted research distinction.

## UI and data handling

Use one responsive operator page: setup/import and camera controls, raw-camera preview with marker/fixture/endpoint overlays, signed overlap and X/Z diagnostics, current quality/rejection explanation, attempt controls/seating checks, trial history and exports. Give screen-reader-readable status, labeled controls, keyboard operation and textual validity indicators in addition to color.

A valid numerical display must distinguish exploratory estimates, acquisition candidates, seating-pending captures and accepted trials. Clear the live numeric result when current observations fail; retain historical attempt results in the history.

Retain per-frame observations/geometry/quality/reasons/calibration IDs and all attempt outcomes locally in IndexedDB. Request persistent storage, surface write/quota failures, and require explicit JSON/CSV export for durable research retention. Browser storage can be evicted or cleared; it cannot promise indefinite retention. Indefinite retention is fulfilled by researcher-controlled exported files, with no automatic deletion in the app.

No RGB recording by default. Optional timestamped RGB frame retention requires explicit bench/participant consent selection; export those images only when separately selected. This application has no depth recording. If storage fails, stop the affected attempt rather than silently lose required research evidence.

Export summary CSV and detailed JSON with units/sign conventions, participant/position/roles, every attempt and validity result, stable-window membership, frame timing, geometry, quality/reasons, software version and calibration/profile versions. Optional RGB files must reference frame IDs. Downloaded artifacts remain on the researcher's device; no automatic uploads or analytics.

## Hosting and verification

Serve `web/` as a static GitHub Pages artifact built/tested from this development branch. Keep asset URLs relative to the project subpath. Configure Pages only after a passing application build and runtime smoke check; preserve the existing native workflows and source. Use HTTPS and explicit user camera permission. Show unsupported camera/runtime conditions clearly.

Required evidence before publishing the application increment:

- Browser runtime smoke checks for detection, PnP, refinement and projection APIs; dictionary artwork compatibility with the existing printed markers.
- Independent known-geometry projections recovering poses and metric virtual tips across camera/fixture/body rotations and distortion; signed-gap/overlap, X/Z and transform-direction tests.
- Rejection checks for planar/poorly conditioned observations, duplicate/missing IDs, behind-camera solutions, ambiguity, residual failures, occlusion, stale frames and missing/incompatible calibration.
- Protocol checks for continuous-window reset/median, timeout, seating rejection, swaps, three-in-five completion and incomplete sessions; persistence failure and export checks.
- Browser tests for camera permission/start/stop cancellation, worker failure/visibility handling, accessible controls and Pages subpath loading. Deterministic synthetic inputs prove software behavior only.
- A deployed Pages smoke check for static assets and application startup. Physical camera/browser support, fixture rigidity, anatomical registration, accuracy, repeatability and equipment effects remain open until real experiments supply evidence.

## Sources

- [OpenCV 4.13 JS binding configuration](https://github.com/opencv/opencv/blob/4.13.0/platforms/js/opencv_js.config.py).
- [OpenCV.js build documentation](https://docs.opencv.org/4.13.0/d4/da1/tutorial_js_setup.html).
- Existing project `GLOSSARY.md`, `docs/design-decisions.md`, ADRs 0002–0004 and the researcher protocol in `plan.md`.

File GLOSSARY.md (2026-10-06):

# Behind-the-Back Shoulder Flexibility Measurement

This context describes anatomical fingertip measurements during a behind-the-back shoulder flexibility test.

## Language

**Anatomical fingertip endpoint**:
The furthest point of a participant's middle finger along its length, located by gentle contact with the finger jig's internal stop.
_Avoid_: Jig endpoint, tracking reference

**Jig tracking reference**:
A defined point on a rigid finger jig with a calibrated geometric relationship to the anatomical fingertip endpoint.
_Avoid_: Anatomical fingertip, biological fingertip

**Finger jig**:
A wearable rigid fixture with at least two separated finger registration regions and a fingertip stop, intended to preserve the anatomical endpoint's relationship to a multi-face fiducial reference.

**Hand rigid body**:
The complete rigid tracking structure attached to one hand or middle finger, with at least three uniquely identified fiducial faces whose spatial relationships are fixed.
_Avoid_: Single fingertip marker

**Virtual anatomical fingertip**:
The anatomical endpoint represented relative to the hand rigid body, whose position remains estimable when the biological fingertip is hidden but the rigid reference remains sufficiently observable.
_Avoid_: Directly detected fingertip, point measured through an occluding hand

**Body reference**:
A target on a calibrated, repeatable upper-back mount that establishes the registered body frame for the fingertip score.

**Participant**:
The person performing the behind-the-back shoulder flexibility test.

**Operator**:
The trained person who sets up the measurement and guides the participant.

**Research measurement**:
A recorded test result accompanied by quality evidence for evaluation and analysis.
_Avoid_: Fitness category, validated clinical assessment

**Signed body-Y overlap**:
The lower-hand anatomical endpoint's body-Y coordinate minus the upper-hand anatomical endpoint's body-Y coordinate, with positive body Y directed upward along the torso. Positive values represent projected overlap, negative values represent a projected gap, and zero represents equal body-Y coordinates rather than physical contact.
_Avoid_: Finger separation for a positive score, physical touching for a zero score

**Physical contact**:
Actual contact between the fingers, which cannot be established from signed body-Y overlap alone.

**Alignment offsets**:
The sideways and outward-from-back differences between the two anatomical fingertip endpoints.

**Right-hand-up position**:
A test position in which the right hand reaches down from above and the left hand reaches up from below.

**Left-hand-up position**:
A test position in which the left hand reaches down from above and the right hand reaches up from below.

**Jig-assisted test**:
A behind-the-back shoulder flexibility test performed while wearing the finger jigs and body reference.
_Avoid_: Bare-hand test

**Trial**:
A single measurement attempt for one hand position, including its validity outcome and seating checks.
_Avoid_: Session

**Familiarization attempt**:
A practice attempt before the three scored valid trials for a hand position.

**Position session score**:
The median signed body-Y overlap of three valid trials for the participant's selected hand-up position.
_Avoid_: Best reach, combined left/right score

**Seating check**:
An operator's verification that both finger registration regions remain engaged and the anatomical fingertip remains gently seated against the internal stop.

**Invalidated trial**:
A measurement attempt excluded from scoring because a required condition failed, including detected jig movement.

**Selected hand-up position**:
The right-hand-up or left-hand-up position selected for a participant and kept consistent across repeat visits.

**Jig calibration**:
A versioned definition of a physical jig's fixed face geometry and the anatomical endpoint relative to its common rigid-body reference.

**Jig assignment**:
The association of a physical finger jig with the upper or lower hand for a trial.

**Supported operating range**:
The measurement conditions under which validation demonstrates that the system meets its acceptance requirements.
_Avoid_: Provisional test range

**Stable window**:
A continuous one-second interval in which all required measurement quality checks pass.

**Quality threshold set**:
A versioned collection of bench-derived acceptance limits for measurement quality checks.

**Inter-attempt interval**:
The elapsed time from the end of one attempt to the start of the next, including any rest, setup, or adjustments.
_Avoid_: Verified rest duration

**Anatomical registration**:
The repeatable relationship between a physical fixture and the participant's defined anatomical reference.

**Rigid-body observability**:
The sufficiency of current observed geometry to estimate a reliable rigid-body pose, including pose conditioning, residuals, ambiguity, and depth support.
_Avoid_: Visible marker count alone

**Measurement-definition equivalence**:
Evidence that the instrument's score represents the same quantity under compatible conditions as a reference test's score.
_Avoid_: Equipment-effect validation alone

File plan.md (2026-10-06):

# Finger-to-Finger 3D Measurement System Plan

## 1. Project Goal

Build a robust iPhone-based system that measures the signed distance between the two middle-finger endpoints during a behind-the-back shoulder flexibility test.

The system is a jig-assisted 3D measurement instrument. It estimates anatomical endpoints from calibrated rigid-body references, transforms them into a participant-centered coordinate frame, and reports signed body-Y overlap with alignment and measurement-quality evidence. Direct biological fingertip visibility is not required. Physical contact is distinct from zero projected overlap.

The objective is repeatable, research-grade measurement; this is a target, not a demonstrated accuracy claim. The researcher operates the phone on a stand and assigns one hand-up position per participant at enrollment, maintained across visits. Bare-hand reference categories remain deferred until equipment effects and the reference table's provenance and applicability are established.

Illustrative output only:

```text
Signed body-Y overlap: +46.3 mm
Depth alignment offset: 18.1 mm
Quality status: VALID only if all validated checks pass
```

Negative values represent a projected gap, positive values projected overlap, and zero equal body-Y coordinates. None of these alone establishes physical contact.

---

## 2. Recommended Sensor Architecture

Use the iPhone front TrueDepth system, comprising front RGB and structured-light depth sensing, with synchronized observations, intrinsic parameters, RGB/depth calibration information, and timestamps. Front TrueDepth is the selected close-range architecture; confirm capture support on the specific device before progressing beyond feasibility work. The exact iPhone model remains unselected.

The reference hardware comprises two rigid 3D fiducial structures, each with at least three uniquely identified planar markers on differently oriented faces, and a rigid ChArUco body reference mounted on the upper back.

```text
Synchronized RGB + TrueDepth observations
                  +
Calibrated multi-face rigid-body geometry
                  +
Calibrated virtual anatomical fingertip points
                  +
Participant/body reference + temporal constraints
                  ↓
Signed body-Y overlap + quality evidence
```

Tracking and confidence belong to each complete rigid body rather than an individual marker. No MediaPipe or other AI fingertip estimation is part of core V1. TrueDepth is an observation source with experimentally characterized bias and noise, not perfect ground truth.

---

## 3. Fingertip Hardware

### 3.1 Rigid 3D multi-marker fixture

Each middle finger wears a lightweight rigid fixture containing a repeatable fingertip stop, a multi-face fiducial structure, and known rigid geometry. A hand-mounted alternative is acceptable only if anatomical registration preserves the calibrated fingertip-to-body relationship throughout the test; an unconstrained finger can move relative to a hand fixture and invalidate that relationship.

The initial fixture concept is a dorsal finger jig with registration/support at at least two separated regions, such as the middle and distal phalanges, plus the gentle fingertip stop. The supports must resist relative rotation, flexion, and sliding that would change the calibrated endpoint. A fingertip stop alone is insufficient evidence of rigidity. Evaluate DIP/PIP motion and finger rotation to identify which motions alter the endpoint-to-fixture relationship; do not assume that two contacts eliminate all motion. Final contact locations, fit adjustment, retention, and dimensions remain prototype choices.

Each structure contains at least three planar markers with distinct IDs. Candidate geometry has a central face and two faces inclined approximately 30–45 degrees from it. These are prototype candidates, not finalized dimensions.

A single planar marker can become unusable under severe perspective angle, hand rotation, partial occlusion, blur, or palm-to-palm overlap. Differently oriented faces provide alternative observations of the same calibrated rigid body when one face is hidden or poorly viewed. This is the intended robustness advantage; it must be demonstrated in rotation and occlusion tests, and does not guarantee tracking when all usable faces are hidden.

```text
         [A1: central face]
        /                  \
 [A2: inclined]      [A3: inclined]
        \__________________/
                 |
        dorsal rigid finger jig
           |             |
      middle-region  distal-region
        support         support
                           |
                   fingertip seating stop
                           · virtual anatomical endpoint
```

### 3.2 Virtual measurement endpoint

The measured anatomical reference is the furthest middle-finger point along its length, seated gently against the internal stop. Its position is estimated as a calibrated virtual point in the fixture's common rigid-body frame. The printed marker location and any external nub are tracking/calibration geometry, not the anatomical endpoint.

A candidate sphere or hemispherical nub of approximately 8–12 mm diameter may assist physical calibration, but neither that size nor use of a nub is finalized. Distinguish its center/surface from the anatomical stop location in calibration records.

### 3.3 Mechanical registration

Minimize fixture slippage, insertion variability, soft-tissue effects, and obstruction during palm-to-palm overlap. The operator checks gentle fingertip seating before and after each trial. Marker visibility does not prove correct seating. Movement of the fixture relative to the finger invalidates the affected trial; reseat and restart.

Seating checks include engagement of both registration regions and the stop. Independently assess endpoint drift during relevant finger motion, removal/remounting, and palm overlap. Multi-region support may alter natural finger posture or reach; evaluate that equipment effect and comfort alongside registration repeatability before accepting the fixture design.

### 3.4 Physical identity and marker IDs

Assign a persistent physical jig ID distinct from its current upper/lower role. Example marker sets are upper structure A1/A2/A3 = 21/22/23 and lower structure B1/B2/B3 = 31/32/33. These are examples; dictionaries and IDs remain configurable until detection testing. Reserve unique IDs across both structures and the body reference.

For rigid body R and marker M_i, calibrate T_R_Mi, the transform mapping marker coordinates into R. Every marker corner then has a known 3D position in R. Store geometry, virtual endpoint, and calibration version by physical jig ID. Confirm role assignments at setup; an observed within-session swap triggers notification, pause, trial invalidation, and researcher confirmation of assignments and seating before restart.

---

## 4. Surface / IR Design

Do not rely on IR spray as the primary tracking method. Select marker-face and candidate endpoint materials experimentally: matte white, light gray, black, and diffuse IR-reflective materials are candidates. Avoid glossy/specular coatings, uncontrolled retroreflective paint, and surfaces that saturate or destabilize depth observations.

Evaluate valid-depth ratio, depth bias/noise, temporal stability, viewing-angle sensitivity, and RGB marker detection. Test individual faces and transitions between visible faces. Report measured results rather than illustrative material-performance values. Final material and geometry choices must precede bench validation.

---

## 5. Body Reference

Mount a rigid ChArUco board or equivalent calibrated multi-marker reference on the upper back. Its pose establishes the participant-centered frame and accounts for phone tilt and participant orientation while sufficiently observed and correctly registered to the torso.

Define a right-handed frame: +Y superior along the back, +Z outward from the back/reference plane, and +X lateral in the direction completing the right-handed frame (+Y × +Z). Record board orientation and torso registration. A board frame is not automatically an anatomical frame if mounting is misaligned.

```text
              +Y (superior)
                   ↑
         -X ←───────┼───────→ +X
                   ↓
                  -Y
       +Z outward from the back
```

Select secure mounting and visibility through prototypes. Board slippage and soft-tissue motion are uncertainty sources. Reject frames when the body reference lacks a valid current observation; do not silently use an old pose.

Treat the upper-back mount as a calibrated fixture. Prototype a lightweight repeatable harness or multi-contact mounting method with documented contact locations and superior-axis alignment; simple attachment to clothing is not evidence of anatomical registration. Verify remount repeatability and board-to-torso angular drift during the pose. Invalidate an affected trial when mounting validity is lost, and re-register before restarting.

If F denotes the fiducial board frame and B the registered body frame, record the mounting calibration T_F_B and calculate T_C_B = T_C_F T_F_B. Identity is permissible only when documented registration aligns the frames. Include mounting calibration identity/version with each trial; visibility of the board alone does not prove stable torso registration.

---

## 6. Camera Configuration

The researcher operates the iPhone on a fixed stand approximately centered behind the participant. Start feasibility/bench characterization at 300–600 mm camera-to-target distance; this is a provisional test envelope, not a claimed optimal or supported range. Narrow the supported range if validation fails. Record distance definition, viewing angles, lighting, capture mode, and device model.

Require sufficient visibility of each complete hand rigid body and the body reference. Do not require every face or either anatomical fingertip to be visible. The minimum acceptable face visibility and viewing-angle limits must be determined experimentally.

The alignment overlay reports body-reference observation, upper/lower rigid-body confidence, calibrated operating range, torso orientation, depth/lateral alignment, and depth coverage. Block capture until required checks pass.

---

## 7. Software Stack

### Native iOS measurement engine

Recommended:

- Swift;
- ARKit / AVFoundation;
- OpenCV;
- Accelerate / simd;
- Metal only if needed for performance.

### UI

Option A — fully native SwiftUI.

Option B — native measurement engine + web-style UI.

If using React/web technologies, keep all sensor access and geometric processing in the native Swift layer.

Do not depend on Safari/PWA for raw TrueDepth access.

---

## 8. Frame Processing Pipeline

For each synchronized RGB/depth pair, retain timestamps and calibration metadata and perform:

```text
RGB → all visible marker IDs → refined corners
                             ↓
           common rigid-body pose from known 3D corners
                             ↘
Depth → RGB/depth registration → valid 3D samples
                             ↓
           separate surface/plane fits per visible face
                             ↙
        quality-weighted RGB/depth/geometry/temporal fusion
                             ↓
  upper rigid-body pose + lower rigid-body pose + body pose
                             ↓
          calibrated virtual anatomical fingertip points
                             ↓
       body-frame transform → signed ΔY + ΔX/ΔZ QC
                             ↓
      observed-frame validity → continuous stable window
```

The curved/multi-face structure must not be treated as a single plane. Log failures and missing estimates explicitly rather than substituting zeros or purely predicted endpoints.

---

## 9. RGB Pose Estimation

Detect all visible fiducials, identify IDs, refine corners to subpixel precision, and use physically measured dimensions and calibrated face transforms. Group observations by physical rigid body and estimate one common 6-DoF pose using all its valid visible corners with solvePnP or an equivalent calibrated estimator. Do not independently estimate and average several marker poses.

Notation throughout this methodology: T_A_B maps coordinates from frame B into frame A. C denotes camera, R a hand rigid body, F the fiducial board, and B the registered participant/body frame. Thus T_C_R maps rigid-body coordinates into camera coordinates.

For known corner P_j^R = T_R_Mi P_j^Mi and observed pixel p_j:

```text
T_C_R* = argmin_T Σ_j ρ(||p_j - π(K, distortion, T P_j^R)||²)
```

Here π is calibrated projection, K is the intrinsic matrix, and ρ is a robust loss whose implementation is documented. Report contributing IDs, visible-face count, corner quality, reprojection residuals, pose confidence, and ambiguity handling. One face may be usable with reduced confidence only if validation supports it; multiple faces do not automatically guarantee high confidence. Severe tilt, small image area, blur, occlusion, or ambiguous/poorly conditioned pose must reduce confidence or invalidate the observation.

---

## 10. TrueDepth Processing

For each currently visible face, map its RGB region into the depth domain using verified registration. Reject invalid samples and use applicable capture-quality metadata. Convert multiple valid depth samples into calibrated camera-frame 3D points; record depth units and whether conversion uses axial depth or another representation.

Fit each visible planar face robustly, excluding edges, unrelated hand/background surfaces, and mixed-depth pixels. Estimate depth residuals, local variance, plane normal, valid-pixel ratio, and temporal consistency. The face's known orientation in R constrains its predicted geometry under T_C_R. Do not use a single depth pixel or fit one plane across differently oriented faces.

Characterize TrueDepth bias, noise, angle dependence, usable range, and registration error experimentally. Depth samples independently constrain geometry but do not constitute ground truth.

---

## 11. RGB + Depth Fusion

Estimate each common hand pose through quality-weighted fusion of image observations, measured depth, known geometry, and temporal constraints:

```text
T* = argmin_T [w_rgb E_rgb + w_depth E_depth
             + w_plane E_plane + w_rigid E_rigid + w_time E_temporal]
```

- E_rgb: residual between observed corners and projected known rigid-body corners.
- E_depth: residual between measured 3D samples and predicted visible-face geometry.
- E_plane: disagreement between observed local normals and transformed calibrated face normals.
- E_rigid: inconsistency with fixed face geometry if separate face variables are estimated.
- E_temporal: implausible changes relative to previously observed poses.

With a single common pose and fixed geometry, rigidity is enforced by construction; E_rigid need not be a separate nonzero penalty. Document the parameterization, robust losses, residual units/scales, and optimizer. Do not average RGB and depth or require fixed equal weights.

RGB confidence uses reprojection error, marker area, sharpness, corner quality, viewing angle, and visible-face count. Depth confidence uses valid coverage, variance, temporal stability, incidence angle, and RGB/depth disagreement. Reduce the contribution of poor observations; reject frames when critical information is absent or sensor disagreement exceeds bench-derived, versioned limits. Temporal regularization cannot make an unobserved rigid body valid.

---

## 12. Rigid-Body-to-Fingertip Calibration

For every physical jig, calibrate each face transform T_R_Mi and the homogeneous anatomical endpoint:

```text
P_tip^R = [x_tip, y_tip, z_tip, 1]^T
P_tip^C = T_C_R P_tip^R
```

The virtual point corresponds to the agreed distal anatomical endpoint gently registered against the stop. Calibration of rigid jig geometry does not prove repeatable anatomical placement; evaluate insertion, remounting, slippage, and any finger motion relative to the fixture separately.

Store physical jig identity, face IDs/dictionary, measured dimensions, transforms, stop/endpoint definition, units, coordinate conventions, calibration method, version, date, and verification evidence. Block measurement for missing or invalid calibration. Recalibrate after marker movement, damage, mounting changes, or endpoint/stop geometry changes. Calibration remains attached to the physical jig when its assigned hand role changes.

---

## 13. Body Coordinate Transformation

Estimate the currently observed body-reference pose T_C_B using calibrated ChArUco geometry and verified RGB/depth consistency. Apply the convention established in Section 9:

```text
P_tip^B = inverse(T_C_B) P_tip^C
         = inverse(T_C_B) T_C_R P_tip^R
```

Apply this separately to upper- and lower-hand endpoints. Use consistent metric units and timestamps; log both camera-frame and body-frame coordinates. Orientation compensation is valid only within the experimentally supported range and with secure anatomical board registration.

---

## 14. Primary Measurement

Let A denote the upper-hand endpoint and L the lower-hand endpoint, with both expressed in body coordinates. Roles are assignments, not permanent physical marker identities.

```text
ΔX = X_L - X_A
ΔY = Y_L - Y_A
ΔZ = Z_L - Z_A
D = ΔY
D_3D = sqrt(ΔX² + ΔY² + ΔZ²)
```

With +Y superior: D < 0 is projected gap, D > 0 is projected overlap, and D = 0 is equal Y coordinates. For example, -35 mm is a 3.5 cm projected gap and +42 mm a 4.2 cm projected overlap. Zero must not be labeled physical touching solely from this score; lateral/depth offsets may remain nonzero.

Use signed ΔY as the primary flexibility score. Report ΔX and ΔZ as alignment/QC quantities and D_3D as a diagnostic quantity, not the primary score. The trial score is the median of valid observed-frame D values in the required stable window.

Before comparison with any published normative table, establish measurement-definition equivalence: source population, test posture and hand assignment, anatomical endpoints, measurement direction, sign/units, alignment rules, and trial aggregation. Determine whether the published score is projected overlap, an along-finger measurement, or another distance. Test lateral/depth offset cases explicitly: +40 mm projected overlap with separated fingers cannot automatically be interpreted as +40 mm under an external protocol. Use paired protocol measurements to assess agreement; equipment-effect validation alone is insufficient. Until equivalence is supported, retain the jig-assisted body-Y score without normative category labels.

The researcher assigns one hand-up position per participant at enrollment and keeps it consistent across visits. Use one familiarization attempt, then at most five scored attempts to obtain three valid trials. Preserve unsuccessful attempts; the position session score is the median of the three valid trial scores. If fewer than three are valid, mark the position incomplete and issue no position session score. Do not combine left/right scores or label results with unvalidated reference categories.

---

## 15. Depth-Alignment and Occlusion Checks

Reject or pause capture when |ΔZ| or lateral offset exceeds experimentally validated protocol limits. A small image-space gap is insufficient evidence of acceptable 3D alignment. Suggested feedback: "Hands are too far apart in depth. Adjust the hand position and hold still." Do not invent final alignment thresholds.

### Palm-to-palm overlap and complete fingertip occlusion

The biological fingertip may be occluded while its position remains estimable through the calibrated rigid-body reference. If the rigid-body reference itself becomes unobservable, the frame is rejected.

```text
Visible faces on each rigid body
             ↓
Fused currently observed common poses
             ↓
Calibrated rigid-body-to-tip points
             ↓
Estimated anatomical fingertip locations
```

This applies to touch, overlap, and palm-to-palm configurations only while sufficient current fiducial observations and depth/QC evidence exist for both structures and the body reference. It is not measurement through an occluding hand. Temporal predictions can aid detection continuity or a clearly labeled preview; purely extrapolated endpoints never contribute valid measurement frames. Recovered observation starts a new continuous passing window.

---

## 16. Temporal Filtering

Require one continuous second of passing observed-frame quality checks. Validate capture rate and timestamp continuity experimentally; do not assume a fixed 30/60-frame count. Missing or invalid observations, capture discontinuities, excessive motion, sensor disagreement, or any required check failure reset the window.

For every frame retain upper/lower/body poses, estimated virtual endpoints, signed ΔY, ΔX, ΔZ, RGB/depth residuals, quality flags, and hand/body velocities. Calculate the trial score as the median signed overlap in the passing window and retain dispersion such as median absolute deviation as quality evidence, not a validated accuracy bound.

The researcher starts each attempt. Capture automatically when the passing window is complete, then require post-trial seating confirmation. A provisional 15-second acquisition timeout or earlier operator stop creates an unsuccessful attempt counted toward the five-attempt limit. The timeout does not apply to subsequent seating confirmation. Rest duration is at the researcher's discretion; log timestamps and elapsed inter-attempt intervals, which may include setup and adjustments.

---

## 17. Automatic Measurement State Machine

```text
SEARCHING → ALIGNING → READY
                       ↓ researcher starts + pre-trial seating check
                  HOLD STILL → MEASURING (continuous 1 s)
                                      ↓
                     VALIDATING (post-trial seating check)
                                      ↓
                                    RESULT
```

READY requires valid calibration, confirmed physical-jig roles, verified body-reference mounting registration, an observed body reference, sufficient upper/lower rigid-body confidence, supported geometry, adequate depth coverage, and passing RGB/depth alignment checks. MEASURING additionally requires low hand/body motion and continuous valid observations. Operator-reported mounting loss invalidates the affected trial; do not assume optical tracking automatically detects mount-to-torso slippage.

A critical failure resets the stable window and returns to alignment/hold while the acquisition timeout continues. On timeout or early stop, save an unsuccessful outcome. Jig swaps or slippage notify, pause, and invalidate the attempt; confirm assignments/seating before starting a new attempt. A failed post-trial seating check invalidates the captured trial. Researchers may save failed observations but cannot override quality failures to produce valid scores.

---

## 18. Measurement QC

Show live quality for the complete upper/lower rigid bodies and body reference, including contributing marker IDs/counts, reprojection error, depth valid ratio and residuals, plane-normal consistency, sensor disagreement, torso motion/orientation, hand velocity, and ΔX/ΔZ alignment. Report stable elapsed time and observed-frame counts.

Fewer visible faces may lower confidence; all faces hidden on either hand means invalid. Experimental visibility criteria, not face count alone, determine acceptance. Store all thresholds in a versioned bench-derived set and log it with each trial. Missing threshold/calibration verification blocks valid research measurement. Preserve failed attempts and explicit failure reasons; do not mask low completion rates by reporting only accepted-frame accuracy.

Define complete rigid-body observability by pose conditioning/ambiguity, image-space corner geometry and resolution, reprojection residuals, and independent depth support. A visible-marker count is descriptive, not an acceptance rule. Record the conditioning measure, its scaling/units, and experimentally chosen limits. Apply the same principle to the body-reference pose and do not let a temporal prior conceal insufficient current geometry.

---

## 19. Uncertainty

No final millimeter-level accuracy or uncertainty is claimed before experimental validation. Display resolution and stable-window dispersion are not accuracy evidence.

Characterize TrueDepth bias/noise, RGB corner localization, camera/depth registration, marker printing, rigid-body face geometry, virtual-tip calibration, mechanical placement, fingertip-stop repeatability, back-reference registration/movement, soft tissue, temporal motion, and partial occlusion.

If uncertainty is reported, derive it from experimentally characterized error propagation or empirical validation/repeatability for the supported conditions, with assumptions, coverage, and confidence interpretation documented. Do not label unvalidated examples as ±1 mm or ±2 mm performance.

---

## 20. Calibration Procedures

### 20.1 Camera/depth verification

Verify intrinsics, distortion behavior, RGB/depth registration, timestamp alignment, depth representation/scale, bias, and noise across candidate distances and angles. Record device, capture mode, verification procedure, and results.

### 20.2 Printed fiducial dimensions

Measure actual marker dimensions and ChArUco square/marker sizes with physical metrology; nominal printer dimensions are insufficient.

### 20.3 Multi-marker rigid-body calibration

Measure every T_R_Mi, marker-corner coordinates, and face orientation in one common frame per physical jig. Verify rigidity and record geometry tolerances and calibration version.

### 20.4 Virtual anatomical endpoint calibration

Determine P_tip^R at the seating stop using documented fixtures/metrology. Record endpoint definition and distinguish optional nub centers/surfaces. Verify before/after seating checks and examine removal/reinstallation effects.

Verify engagement of both finger registration regions and characterize endpoint drift from flexion, rotation, sliding, fit variation, and remounting independently of camera pose error. Record fixture sizing/configuration and mechanical registration verification evidence.

### 20.5 Body-reference calibration

Verify printed geometry, right-handed coordinate convention, superior-axis alignment, secure mounting, and anatomical registration repeatability.

Calibrate the board-to-body mounting transform T_F_B, document harness/contact geometry and orientation procedure, and quantify angular/positional drift during trials and removal/remounting. Evaluate how those errors propagate into ΔY rather than treating a stable board pose as proof of a stable anatomical frame.

### 20.6 Depth bias and mechanical repeatability

Use known-distance targets; candidate distances include 250, 300, 350, 400, 450, 500, and 600 mm. Values outside 300–600 mm extend characterization rather than establish supported operation. For each condition record bias, SD, valid coverage, incidence angle, and lighting/material effects. Repeat jig removal, insertion, and reference remounting and quantify their effects.

Archive calibration evidence by physical jig and device/configuration. Changed marker, stop, or mounting geometry requires recalibration. Determine acceptance limits and verification frequency through experiments and document them before scored research use.

---

## 21. Validation Plan

Use an independently characterized precision reference, such as a calibrated caliper, gauge blocks, linear stage, or mechanical fixture. Specify reference uncertainty, coordinate registration, endpoint definition, repetitions, and test conditions before validation. TrueDepth is not the validation reference.

### Phase A — Static bench test

Test signed overlaps -100, -75, -50, -25, 0, +25, +50, +75, and +100 mm within the provisional camera-distance envelope of 300–600 mm. Repeat at documented distances, viewing angles, lighting, and materials. Evaluate accepted engineering targets throughout the envelope, report condition-specific failures, and narrow supported conditions if needed.

### Phase B — Hand rigid-body rotation

Rotate each structure through relevant orientations; quantify detection/pose error against known geometry and performance versus visible-face count and angle, including one-face and multi-face configurations. Establish experimentally which observations are usable.

### Phase C — Systematic occlusion

Cover one face, two faces, part of a rigid body, one anatomical fingertip, and both fingertips. Verify preserved accuracy when references remain observable, appropriate confidence reduction, and rejection when either rigid body or the body reference lacks sufficient current observation. Test that extrapolated frames do not enter a valid stable window.

### Phase C.1 — Complete rigid-body observability experiment

Use known rigid-body poses and systematically vary the number and arrangement of observed corners, face-normal diversity, projected target size, viewing angle, partial-face occlusion, blur, and depth coverage. Include three well-resolved faces, two faces with distinct normals, one frontal face, one highly oblique face, and two tiny/partially visible faces. These are test cases, not predetermined PASS/REJECT labels; missing corners must not be fabricated.

Compare estimated pose and resulting endpoint/ΔY error with the precision reference. Record pose-conditioning/ambiguity indicators, reprojection residuals, depth support, and acceptance/rejection outcomes, including apparently low-residual but ambiguous solutions. Derive a versioned joint observability rule from these experiments and verify it on separate conditions/repetitions not used to tune the rule. Reject geometrically insufficient cases even when a nominal marker-count threshold would pass.

### Phase D — Overlap and palm-to-palm configurations

Test increasing projected overlaps, for example 0, +10, +20, +30, and +50 mm, and severe overlap within the broader test envelope. Record marker visibility and any fixture interference. Zero projected overlap is not a physical-touch ground-truth label.

### Phase E — Depth-offset test

Hold true body-Y overlap fixed while varying ΔZ and lateral alignment. Quantify Y-score sensitivity and establish alignment limits according to the protocol; evaluate correct rejection as well as accepted-result accuracy.

### Phase F — Body-reference rotation

Keep true endpoint geometry fixed and vary yaw, pitch, and roll. Initial candidate angles from the original plan are yaw ±20 degrees and pitch/roll ±15 degrees. Verify transformation stability and characterize limits rather than assume these angles are supported.

Separately perturb/remount the body-reference fixture relative to the torso surrogate while keeping endpoint geometry fixed. Quantify body-axis registration error and its effect on ΔY, then evaluate drift/remounting on participants during consented pilots. Board visibility and camera-relative pose quality do not replace mounting validity.

### Phase G — Human repeatability and equipment effects

Bench acceptance for static distance, depth offsets, and rotation is required before scored human research measurements; occlusion/overlap behavior must also support intended use. Earlier consented setup/comfort pilots remain exploratory. Assess repeat visits, operator effects, cap removal/reinstallation, back-reference mounting, and effects on reach/comfort versus the intended bare-hand test. Keep the assigned hand-up position consistent and follow the three-valid-trial protocol.

Evaluate multi-region finger registration and mounting effects independently from optical tracking. For any intended normative comparison, add paired measurements under the source test definition and the instrument protocol, including alignment edge cases, and establish measurement-definition agreement before applying published categories.

### Phase H — External ground-truth comparison

If available, compare against Qualisys/Vicon, calibrated stereo vision, or a precision mechanical fixture with documented reference error. Interpret results within each method's limitations. Human repeatability and equipment effects must be assessed before accuracy claims or bare-hand reference categories are used.

---

## 22. Performance Metrics

### Accuracy and provisional engineering acceptance

Report MAE, RMSE, signed systematic bias, SD of errors, and 95% limits of agreement against the precision reference. Accepted provisional bench targets are MAE ≤ 5 mm, absolute bias ≤ 2 mm, and repeated static measurement SD ≤ 2 mm across agreed conditions. These are requirements to test, not established capabilities.

### Repeatability

Report within-window/within-trial dispersion, repeated static trial SD, between-trial and remount SD, and operator/visit effects. Report ICC where appropriate with its model and confidence interval. Coefficient of variation is unsuitable near zero or across signed gap/overlap values; prioritize absolute-unit metrics there.

### Robustness and latency

Report detection success, valid/rejected-frame rates, depth availability, completion rate, and rejection correctness with explicit denominators, including failed attempts. Report FPS and frame-to-result latency.

Stratify performance by visible-tag count, viewing angle, occlusion severity, camera distance, depth quality, signed overlap, and reference/hand orientation. Publish validation sample counts and uncertainty intervals; acceptance on surviving frames alone is insufficient evidence of robustness.

---
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

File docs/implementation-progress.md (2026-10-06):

# Implementation ledger — plan: plan.md

The objective is the complete measurement instrument described in `plan.md`, with verified software milestones pushed to GitHub. Code/build success does not certify physical fixtures, sensor accuracy, or research validity.

## Execution decisions

- Ruling: work on `build/sensor-prototype` in the existing clean checkout — no concurrent edits or user changes existed, and milestone pushes are explicitly authorized. Green deliverables will be published; test-first CI commits on the implementation branch are verification work, not completed milestones.
- Ruling: use macOS GitHub Actions for Swift tests and iOS builds — this Windows host has neither Swift nor Xcode. Real-device and hardware acceptance remain open.
- Initial device: iPhone 15 Pro Max. The requested compatibility range extends through iPhone 18; each exact device/capture mode requires runtime capability checks and validation before claiming support.
- Pre-flight: multi-face calibration feeds common-pose estimation; virtual-tip geometry consumes the resulting rigid-body pose; body registration feeds body-frame scoring; the scorer feeds observed-only temporal QC and the three-valid-trial session protocol. All use explicit metric units, persistent physical fixture IDs, and versioned calibration.
- Physical registration gates expanded tracking/fusion software. Minimal native capture/detection tools and fixture experiments proceed first; no invented fixture dimensions or validation data substitute for that gate.
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

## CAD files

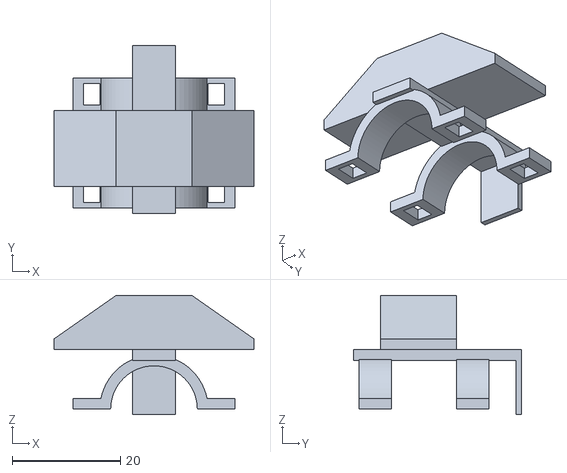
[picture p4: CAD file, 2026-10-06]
hardware/prototypes/finger-fixture-candidate.stl
36.9 x 31.0 x 22.0

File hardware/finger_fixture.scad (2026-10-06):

// Experimental dorsal middle-finger fixture. Units: mm.
// Nominal dimensions are candidate values, not fit/accuracy claims.
// Frame R: origin at fingertip stop; +Y distal, +Z dorsal, +X lateral.
$fn = 64;
finger_radius_mm = 8;
face_angle_degrees = 35;
wall_mm = 2;
support_spacing_mm = 18;
support_length_mm = 6;
marker_edge_mm = 10;
quiet_zone_mm = 2;
target_height_mm = 10;
face_edge = marker_edge_mm + 2*quiet_zone_mm;
outer_radius = finger_radius_mm + wall_mm;
target_base_z = finger_radius_mm + 3;
outer_half_width = face_edge/2 + face_edge*cos(face_angle_degrees);
side_bottom_z = target_height_mm - face_edge*sin(face_angle_degrees);

assert(finger_radius_mm >= 6 && finger_radius_mm <= 12, "Candidate radius out of experiment range");
assert(face_angle_degrees >= 20 && face_angle_degrees <= 45, "Candidate angle out of experiment range");
assert(side_bottom_z > 0, "Target sides must remain above mounting plane");

module dorsal_support(y) {
    translate([0,y,0]) {
        intersection() {
            difference() {
                rotate([90,0,0]) cylinder(r=outer_radius,h=support_length_mm,center=true);
                rotate([90,0,0]) cylinder(r=finger_radius_mm,h=support_length_mm+2,center=true);
            }
            translate([-outer_radius,-support_length_mm/2,0])
                cube([2*outer_radius,support_length_mm,outer_radius+1]);
        }
        // Strap slots; strap/liner choices require separate fit tests.
        for (sign=[-1,1]) {
            translate([sign*(outer_radius+1.5),0,1]) difference() {
                cube([7,support_length_mm,2],center=true);
                cube([3,support_length_mm-2,4],center=true);
            }
        }
    }
}

module three_face_target() {
    translate([0,-18,target_base_z]) rotate([90,0,0])
        linear_extrude(height=face_edge,center=true)
            polygon(points=[[-outer_half_width,0],[outer_half_width,0],
                [outer_half_width,side_bottom_z],[face_edge/2,target_height_mm],
                [-face_edge/2,target_height_mm],[-outer_half_width,side_bottom_z]]);
}

union() {
    dorsal_support(-8);
    dorsal_support(-8-support_spacing_mm);
    // Dorsal bridge connects both registration regions and the target mount.
    translate([-4,-30,outer_radius-1]) cube([8,31,2]);
    // Stop's proximal surface at Y=0 defines the nominal anatomical tip reference.
    translate([-4,0,-1]) cube([8,1,outer_radius+2]);
    three_face_target();
}

echo(candidate_tip_R_mm=[0,0,0]);
echo(central_face_center_R_mm=[0,-18,target_base_z+target_height_mm]);
echo(right_face_center_R_mm=[face_edge/2+face_edge/2*cos(face_angle_degrees),-18,
    target_base_z+target_height_mm-face_edge/2*sin(face_angle_degrees)]);
echo(left_face_center_R_mm=[-face_edge/2-face_edge/2*cos(face_angle_degrees),-18,
    target_base_z+target_height_mm-face_edge/2*sin(face_angle_degrees)]);

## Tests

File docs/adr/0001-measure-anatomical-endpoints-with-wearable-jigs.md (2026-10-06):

# Measure anatomical endpoints through calibrated wearable jigs

The research prototype will accept two finger caps and a back reference, using calibrated jig geometry to report anatomical middle-finger endpoints rather than rigid jig extensions. This trades the simplicity of a bare-hand test for explicit tracking references and calibration, while requiring experiments to assess whether the equipment changes reach or comfort; the exact anatomical endpoint and calibration procedure remain unresolved.

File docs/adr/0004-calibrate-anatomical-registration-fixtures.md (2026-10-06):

# Verify finger and torso registration as calibrated fixtures

The virtual-tip instrument depends on anatomical registration as well as optical pose estimation, so the next feasibility gate is a multi-region dorsal finger fixture and a repeatable calibrated upper-back mount. These add mechanical complexity and may influence posture or reach, but a fingertip stop or a visible clothing-mounted board alone does not establish the fixed anatomical relationships required by the measurement model. Quantify drift, remount repeatability, and equipment effects before freezing geometry; normative comparison additionally requires measurement-definition equivalence with the source test.

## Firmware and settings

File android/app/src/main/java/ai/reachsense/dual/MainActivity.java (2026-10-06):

package ai.reachsense.dual;

import android.Manifest;
import android.app.Activity;
import android.content.Intent;
import android.content.pm.PackageManager;
import android.graphics.Bitmap;
import android.graphics.Color;
import android.graphics.Typeface;
import android.os.Build;
import android.os.Bundle;
import android.text.InputType;
import android.view.View;
import android.view.WindowInsets;
import android.widget.AdapterView;
import android.widget.ArrayAdapter;
import android.widget.Button;
import android.widget.CheckBox;
import android.widget.EditText;
import android.widget.ImageView;
import android.widget.LinearLayout;
import android.widget.ScrollView;
import android.widget.Spinner;
import android.widget.TextView;
import android.widget.Toast;
import java.io.File;
import java.io.FileInputStream;
import java.io.OutputStream;
import java.nio.charset.StandardCharsets;
import java.util.ArrayList;
import java.util.Arrays;
import java.util.Comparator;
import java.util.List;

public final class MainActivity extends Activity implements DualCapture.Listener {
    private static final int CAMERA_PERMISSION = 1, EXPORT_REPORT = 2;
    private DualCapture capture;
    private LinearLayout content;
    private Spinner pairs, roles, saved;
    private EditText threshold;
    private Button scan, start, stop, export;
    private TextView status;
    private final ImageView[] previews = new ImageView[2];
    private final TextView[] labels = new TextView[2];
    private final CheckBox[] identities = new CheckBox[2];
    private final List<DualCapture.Pair> candidates = new ArrayList<>();
    private final List<File> reports = new ArrayList<>();
    private List<RunReport> pending = new ArrayList<>();
    private RunReport exportingPending;
    private File exporting;
    private byte[] exportingMemory;

    @Override public void onCreate(Bundle state) {
        super.onCreate(state);
        ScrollView scroll = new ScrollView(this);
        scroll.setFillViewport(true); scroll.setBackgroundColor(Color.rgb(244, 247, 251));
        content = new LinearLayout(this); content.setOrientation(LinearLayout.VERTICAL);
        content.setPadding(dp(20), dp(20), dp(20), dp(24)); scroll.addView(content);
        scroll.setOnApplyWindowInsetsListener((view, insets) -> {
            if (Build.VERSION.SDK_INT >= 30) {
                android.graphics.Insets bars = insets.getInsets(WindowInsets.Type.systemBars() | WindowInsets.Type.displayCutout());
                scroll.setPadding(bars.left, bars.top, bars.right, bars.bottom);
            } else scroll.setPadding(insets.getSystemWindowInsetLeft(), insets.getSystemWindowInsetTop(), insets.getSystemWindowInsetRight(), insets.getSystemWindowInsetBottom());
            return insets;
        });
        setContentView(scroll);
        text("ReachSense Dual", 28, true);
        text("S23 Ultra · camera verification", 16, false);
        text("Test two rear lenses together. Reports stay on this phone; preview images are not recorded.", 14, false);
        scan = button("Check cameras", () -> {
            if (requirePendingExport()) return;
            if (cameraPermission()) capture.discover(); else requestPermissions(new String[] {Manifest.permission.CAMERA}, CAMERA_PERMISSION);
        });
        text("1  Select a physical-camera pair", 18, true);
        pairs = new Spinner(this); content.addView(pairs);
        pairs.setOnItemSelectedListener(new Selection() {
            @Override public void onItemSelected(AdapterView<?> parent, View view, int position, long id) { resetPreviews(); }
        });
        text("Maximum image timestamp difference (ms)", 14, false);
        threshold = new EditText(this); threshold.setText("5");
        threshold.setInputType(InputType.TYPE_CLASS_NUMBER | InputType.TYPE_NUMBER_FLAG_DECIMAL);
        threshold.setContentDescription("Exploratory maximum image timestamp difference in milliseconds");
        content.addView(threshold);
        text("Exploratory pairing filter. Exposure synchronization requires separate validation.", 13, false);
        LinearLayout actions = new LinearLayout(this);
        start = new Button(this); start.setText("Start 30-second test"); start.setOnClickListener(v -> begin());
        stop = new Button(this); stop.setText("Stop"); stop.setOnClickListener(v -> { stop.setEnabled(false); capture.stop("researcher_stopped"); });
        actions.addView(start, new LinearLayout.LayoutParams(0, dp(56), 2));
        actions.addView(stop, new LinearLayout.LayoutParams(0, dp(56), 1)); content.addView(actions);
        status = text("Grant camera access and check the available pairs.", 15, false);
        status.setAccessibilityLiveRegion(View.ACCESSIBILITY_LIVE_REGION_POLITE);
        text("2  Verify both lenses", 18, true);
        for (int stream = 0; stream < 2; stream++) {
            labels[stream] = text("Stream " + (stream == 0 ? "A" : "B"), 16, true);
            previews[stream] = new ImageView(this); previews[stream].setBackgroundColor(Color.rgb(18, 29, 44));
            previews[stream].setScaleType(ImageView.ScaleType.FIT_CENTER);
            previews[stream].setContentDescription("Live preview for stream " + (stream == 0 ? "A" : "B"));
            content.addView(previews[stream], new LinearLayout.LayoutParams(-1, dp(220)));
        }
        text("Cover each physical lens in turn. Only its assigned preview should be obscured. Use the FOV and lens location to assign wide/ultrawide.", 14, false);
        roles = new Spinner(this);
        roles.setAdapter(new ArrayAdapter<>(this, android.R.layout.simple_spinner_dropdown_item,
            new String[] {"Choose lens roles after checking", "A = wide · B = ultrawide", "A = ultrawide · B = wide"}));
        content.addView(roles);
        roles.setOnItemSelectedListener(new Selection() {
            @Override public void onItemSelected(AdapterView<?> parent, View view, int position, long id) {
                for (CheckBox box : identities) if (box != null) { box.setChecked(false); box.setEnabled(capture != null && capture.isRunning() && position > 0); }
                if (capture != null) capture.assignRoles(position);
            }
        });
        for (int stream = 0; stream < 2; stream++) {
            final int index = stream;
            identities[stream] = new CheckBox(this);
            identities[stream].setText("I verified lens " + (stream == 0 ? "A" : "B") + " by covering it");
            identities[stream].setMinHeight(dp(48)); content.addView(identities[stream]);
            identities[stream].setOnCheckedChangeListener((view, checked) -> { if (capture != null) capture.confirm(index, checked); });
        }
        text("3  Export the evidence", 18, true);
        saved = new Spinner(this); content.addView(saved);
        export = button("Export selected JSON report", this::exportReport);
        text("A complete run demonstrates stream delivery. Stereo matching still needs camera calibration and an optical timing test, especially when synchronization is approximate or unknown.", 13, false);
        capture = new DualCapture(this, this);
        controls(false); refreshReports(null);
        if (state != null) {
            String name = state.getString("export_file");
            for (File file : reports) if (file.getName().equals(name)) exporting = file;
            String id = state.getString("export_pending_id");
            for (RunReport report : pending) if (report.data.optString("id").equals(id)) {
                exportingPending = report; exportingMemory = report.data.toString().getBytes(StandardCharsets.UTF_8);
            }
        }
        if (!requirePendingExport() && cameraPermission()) capture.discover();
    }
    private void begin() {
        if (requirePendingExport()) return;
        if (!cameraPermission()) { requestPermissions(new String[] {Manifest.permission.CAMERA}, CAMERA_PERMISSION); return; }
        int selection = pairs.getSelectedItemPosition();
        if (selection < 0 || selection >= candidates.size()) { status.setText("Check cameras and select an available pair first."); return; }
        try {
            long limit = TimingEvidence.pairingLimitNs(Double.parseDouble(threshold.getText().toString().trim()));
            roles.setSelection(0); resetPreviews();
            status.setText("Opening two physical-camera outputs…");
            capture.start(candidates.get(selection), limit); controls(true);
        } catch (IllegalArgumentException error) { threshold.setError(error.getMessage()); }
    }
    private void controls(boolean running) {
        boolean needsExport = !RunReport.pendingSnapshot().isEmpty();
        scan.setEnabled(!running && !needsExport); pairs.setEnabled(!running); threshold.setEnabled(!running);
        start.setEnabled(!running && !needsExport && !candidates.isEmpty()); stop.setEnabled(running); roles.setEnabled(running);
        for (CheckBox box : identities) box.setEnabled(running && roles.getSelectedItemPosition() > 0);
        saved.setEnabled(!running); export.setEnabled(!running && (!reports.isEmpty() || !pending.isEmpty()));
        if (running) getWindow().addFlags(android.view.WindowManager.LayoutParams.FLAG_KEEP_SCREEN_ON);
        else getWindow().clearFlags(android.view.WindowManager.LayoutParams.FLAG_KEEP_SCREEN_ON);
    }
    private void resetPreviews() {
        int position = pairs.getSelectedItemPosition();
        for (int stream = 0; stream < 2; stream++) {
            if (previews[stream] != null) previews[stream].setImageDrawable(null);
            if (identities[stream] != null) identities[stream].setChecked(false);
            if (labels[stream] != null) labels[stream].setText("Stream " + (stream == 0 ? "A" : "B")
                + (position >= 0 && position < candidates.size() ? " · " + candidates.get(position).label(stream) : ""));
        }
    }
    @Override public void inventory(List<DualCapture.Pair> available, String message) {
        candidates.clear(); candidates.addAll(available);
        pairs.setAdapter(new ArrayAdapter<>(this, android.R.layout.simple_spinner_dropdown_item, candidates));
        status.setText(message); controls(false); resetPreviews();
    }
    @Override public void preview(int stream, Bitmap bitmap) { previews[stream].setImageBitmap(bitmap); }
    @Override public void status(String message) { status.setText(message); }
    @Override public void finished(RunReport report, File file, String message) {
        org.json.JSONObject summary = report.data.optJSONObject("summary");
        String exposure = "Exposure synchronization unknown; optical timing test required.";
        if (summary != null && summary.optString("exposure_synchronization").startsWith("hardware_calibrated"))
            exposure = "Hardware-calibrated synchronization reported; stereo validation still required.";
        else if (summary != null && summary.optString("exposure_synchronization").startsWith("approximate"))
            exposure = "Approximate synchronization reported; optical timing test required.";
        status.setText(message + (summary == null ? "" : "\n" + summary.optInt("matched_pairs") + " image timestamp pairs.") + "\n" + exposure);
        refreshReports(file); controls(false);
    }
    private void refreshReports(File preferred) {
        pending = RunReport.pendingSnapshot();
        File[] files = new File(getFilesDir(), "reports").listFiles((dir, name) -> name.endsWith(".json"));
        reports.clear();
        if (files != null) {
            Arrays.sort(files, Comparator.comparingLong(File::lastModified).reversed());
            reports.addAll(Arrays.asList(files));
        }
        List<String> names = new ArrayList<>();
        for (RunReport report : pending) names.add("Unsaved — " + report.data.optString("id").substring(0, 8) + " — export now");
        java.text.DateFormat date = java.text.DateFormat.getDateTimeInstance(java.text.DateFormat.SHORT, java.text.DateFormat.MEDIUM);
        for (File report : reports) names.add(date.format(new java.util.Date(report.lastModified())) + " · " + report.getName().substring(4, 12));
        saved.setAdapter(new ArrayAdapter<>(this, android.R.layout.simple_spinner_dropdown_item, names));
        if (preferred != null && reports.contains(preferred) && pending.isEmpty()) saved.setSelection(reports.indexOf(preferred));
        export.setEnabled(!reports.isEmpty() || !pending.isEmpty());
    }
    private void exportReport() {
        int selection = saved.getSelectedItemPosition();
        if (selection < 0) return;
        exportingMemory = null; exporting = null; exportingPending = null;
        if (selection < pending.size()) {
            exportingPending = pending.get(selection);
            exportingMemory = exportingPending.data.toString().getBytes(StandardCharsets.UTF_8);
        }
        else {
            int index = selection - pending.size();
            if (index >= 0 && index < reports.size()) exporting = reports.get(index);
        }
        if (exporting == null && exportingMemory == null) return;
        Intent document = new Intent(Intent.ACTION_CREATE_DOCUMENT).addCategory(Intent.CATEGORY_OPENABLE).setType("application/json");
        document.putExtra(Intent.EXTRA_TITLE, exporting == null ? "reachsense-unsaved-report.json" : exporting.getName());
        try { startActivityForResult(document, EXPORT_REPORT); }
        catch (RuntimeException error) { status.setText("Cannot open export picker: " + error.getMessage()); }
    }
    @Override protected void onActivityResult(int request, int result, Intent data) {
        super.onActivityResult(request, result, data);
        if (request != EXPORT_REPORT || result != RESULT_OK || data == null || data.getData() == null) return;
        try {
          try (OutputStream output = getContentResolver().openOutputStream(data.getData())) {
            if (output == null) throw new java.io.IOException("Destination is unavailable");
            if (exportingMemory != null) output.write(exportingMemory);
            else if (exporting != null) try (FileInputStream input = new FileInputStream(exporting)) {
                byte[] buffer = new byte[8192]; int length;
                while ((length = input.read(buffer)) != -1) output.write(buffer, 0, length);
            } else throw new java.io.IOException("Report selection was interrupted. Select and export it again.");
          }
            if (exportingPending != null) RunReport.pendingExported(exportingPending);
            refreshReports(null); controls(false);
            Toast.makeText(this, "Report exported", Toast.LENGTH_SHORT).show();
        } catch (Exception error) { status.setText("Export failed. The original report is retained: " + error.getMessage()); }
    }
    @Override public void onRequestPermissionsResult(int request, String[] permissions, int[] results) {
        super.onRequestPermissionsResult(request, permissions, results);
        if (request != CAMERA_PERMISSION) return;
        if (cameraPermission()) capture.discover();
        else {
            status.setText("Camera permission was denied. Allow it in Settings → Apps → ReachSense Dual → Permissions, then check cameras again.");
            capture.diagnostic("permission_denied", "Camera access denied by user or system");
        }
    }
    @Override protected void onPause() { if (capture != null && capture.isRunning()) capture.stop("backgrounded"); super.onPause(); }
    @Override protected void onResume() {
        super.onResume();
        if (capture != null && !capture.isRunning()) { refreshReports(null); controls(false); }
    }
    @Override protected void onSaveInstanceState(Bundle state) {
        if (exporting != null) state.putString("export_file", exporting.getName());
        if (exportingPending != null) state.putString("export_pending_id", exportingPending.data.optString("id"));
        super.onSaveInstanceState(state);
    }
    @Override protected void onDestroy() { if (capture != null) capture.close(); super.onDestroy(); }
    private boolean cameraPermission() { return checkSelfPermission(Manifest.permission.CAMERA) == PackageManager.PERMISSION_GRANTED; }
    private boolean requirePendingExport() {
        if (RunReport.pendingSnapshot().isEmpty()) return false;
        refreshReports(null); controls(false);
        status.setText("Local storage failed. Keep the app open and export every pending report before starting another check.");
        return true;
    }
    private TextView text(String value, int size, boolean bold) {
        TextView view = new TextView(this); view.setText(value); view.setTextSize(size);
        view.setTextColor(Color.rgb(25, 39, 55)); view.setPadding(0, dp(bold ? 18 : 8), 0, dp(8));
        if (bold) view.setTypeface(Typeface.DEFAULT, Typeface.BOLD);
        content.addView(view); return view;
    }
    private Button button(String label, Runnable action) {
        Button button = new Button(this); button.setText(label); button.setMinHeight(dp(52));
        button.setOnClickListener(view -> action.run()); content.addView(button); return button;
    }
    private int dp(int value) { return Math.round(value * getResources().getDisplayMetrics().density); }
    private abstract static class Selection implements AdapterView.OnItemSelectedListener {
        @Override public void onNothingSelected(AdapterView<?> parent) { }
    }
}

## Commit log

2026-10-06 Build front TrueDepth feasibility viewer and calibrated frame export
2026-10-06 Add fixture feasibility CAD and test capture lifecycle safeguards
    [finger_fixture.scad]
2026-10-06 Fix capture cancellation and freshness; retain bench tools and fixture candidate
    [finger-fixture-candidate.stl]
2026-10-06 Record verified sensor software milestone and remaining physical gates
2026-10-06 Define calibrated RGB web application architecture
2026-10-06 Build local RGB camera instrument and Pages workflow
2026-10-06 Preserve in-flight records and invalidate changed camera bindings
2026-10-06 Specify S23 Ultra dual-camera capture and timing verification
2026-10-06 Plan Android dual-camera APK implementation and device checks
2026-10-06 Add tested one-to-one Android camera timing evidence
2026-10-06 Build native Android dual-camera capture and evidence APK
2026-10-06 Correct Android version configuration and API compatibility guard
    [MainActivity.java]
2026-10-06 Reject stale completion and retain every failed-save report
    [MainActivity.java]
2026-10-06 Record verified Android APK and pending S23 device acceptance
